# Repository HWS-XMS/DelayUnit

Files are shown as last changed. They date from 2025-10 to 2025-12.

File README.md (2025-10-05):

# Precision Trigger Delay System

Configurable digital delay system for Xilinx FPGAs with 5ns resolution.

## Features

- **Resolution**: 5ns (200MHz clock)
- **Delay Range**: 0 to 21.5 seconds
- **Configurable Output Width**: 5ns to any duration
- **Control**: UART @ 1Mbaud with Python API
- **Supported Platforms**:
  - Digilent Arty A7-35T (XC7A35T)
  - Digilent Nexys Video (XC7A200T)

## Quick Start

### Build & Program

Navigate to your target board directory and use the local Makefile:

**For Arty A7:**
```bash
cd targets/arty
make synth         # Synthesize design
make program       # Program FPGA (volatile)
make flash         # Program SPI flash (persistent)
```

**For Nexys Video:**
```bash
cd targets/nexys
make synth         # Synthesize design
make program       # Program FPGA (volatile)
make flash         # Program SPI flash (persistent)
```

### Python Control

```python
from delay_unit import DelayUnit, EdgeType

with DelayUnit() as unit:
    unit.delay_ns = 100
    unit.width_ns = 50
    unit.soft_trigger()
    print(unit.status)
```

### Testing

```bash
cd python
python test_comprehensive.py  # 1000 test combinations
```

## Hardware Setup

### Arty A7-35T

**Soft Trigger Testing:**
- Jumper: JA Pin 3 → JA Pin 1
- Scope Ch1: JA Pin 3 (trigger)
- Scope Ch2: JA Pin 2 (delayed output)

**Pmod JA Pinout:**
- Pin 1 (G13): External trigger input
- Pin 2 (B11): Delayed trigger output
- Pin 3 (A11): Soft trigger output

### Nexys Video (XC7A200T)

**Soft Trigger Testing:**
- Jumper: JA Pin 3 → JA Pin 1
- Scope Ch1: JA Pin 3 (trigger)
- Scope Ch2: JA Pin 2 (delayed output)

**Pmod JA Pinout:**
- Pin 1 (AB22): External trigger input
- Pin 2 (AB21): Delayed trigger output
- Pin 3 (AB20): Soft trigger output

## Architecture

- **CDC_EDGE_DETECT**: Clock domain crossing with edge detection
- **CONFIGURABLE_DELAY**: Programmable delay with configurable output width
- **UART_RX/TX**: UART communication @ 1Mbaud
- **Clock**: 100MHz input → 200MHz system clock via MMCM

## UART Commands

| Command | Code | Data | Description |
|---|---|---|---|
| SET_COARSE | 0x01 | 4 bytes | Set delay (cycles) |
| GET_COARSE | 0x02 | - | Get delay |
| SET_WIDTH | 0x08 | 4 bytes | Set output width (cycles) |
| GET_WIDTH | 0x09 | - | Get output width |
| SOFT_TRIGGER | 0x07 | - | Generate trigger |
| GET_STATUS | 0x05 | - | Get trigger count + delay |
| RESET_COUNT | 0x06 | - | Reset counter |

## License

MIT

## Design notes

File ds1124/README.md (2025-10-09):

# DS1124 8-Bit Programmable Delay Line Driver

SystemVerilog implementation of a driver for the DS1124 programmable delay IC.

## ⚠️ Important Hardware Requirements

**The DS1124 operates at 5V logic levels.** Most modern FPGAs use 3.3V or 1.8V I/O standards, therefore:

### Control Interface Level Shifting
- **Level shifters are REQUIRED** between FPGA and DS1124
- Use bidirectional level shifters for the Q signal (if readback is used)
- Use unidirectional level shifters for CLK, D, and E signals (FPGA → DS1124)
- Ensure level shifters can handle the serial clock frequency (up to 10 MHz)

### Signal Path Level Shifting
- **The actual signal to be delayed ALSO requires level shifting:**
  - INPUT: FPGA output (3.3V/1.8V) → Level Shifter → DS1124 IN (5V)
  - OUTPUT: DS1124 OUT (5V) → Level Shifter → FPGA input (3.3V/1.8V)
- These signal path level shifters must support the full bandwidth of your delayed signal
- Use high-speed level shifters for critical timing paths

Example level shifters:
- TXB0104 (4-channel bidirectional, auto-direction, up to 100 Mbps)
- SN74LVC1T45 (single channel bidirectional, up to 420 Mbps)
- SN74LVC2T45 (dual channel bidirectional)
- SN74LVC1G125 (single channel unidirectional, high-speed)

## Files

- `ds1124_driver.sv` - Main driver module
- `ds1124_driver_tb.sv` - Comprehensive testbench
- `test_*.sv` - Auxiliary test files for specific features

## Features

- 8-bit delay control (0-255 steps, 0.25ns per step)  
- 3-wire serial interface (CLK, D, E)
- Configurable system clock frequency
- Optional non-destructive readback
- Automatic settling time calculation

## Usage

```systemverilog
ds1124_driver #(
    .SYS_CLK_FREQ(100_000_000),  // 100 MHz
    .CLK_DIV(4),                  // Divide by 4
    .READBACK_EN(1)               // Enable readback
) u_ds1124 (
    .clk(clk),
    .rst(rst),
    .delay_value(delay_value),
    .en(en),
    .ready(ready),
    .ds1124_clk(ds1124_clk),
    .ds1124_d(ds1124_d),
    .ds1124_e(ds1124_e),
    .ds1124_q(ds1124_q),
    .read_delay(read_delay),
    .current_delay(current_delay),
    .read_valid(read_valid)
);
```

## Testing

Run the comprehensive testbench:
```bash
iverilog -g2012 -o ds1124_tb ds1124_driver.sv ds1124_driver_tb.sv
vvp ds1124_tb
```

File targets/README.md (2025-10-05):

# Board Targets

This directory contains board-specific build configurations for the Precision Trigger Delay System.

## Available Targets

### arty/
Digilent Arty A7-35T (XC7A35TICSG324-1L)
- 100MHz system clock → 200MHz via MMCM
- Pmod JA connections for trigger I/O
- USB-UART for control interface

### nexys/
Digilent Nexys Video (XC7A200TSBG484-1)
- 100MHz system clock → 200MHz via MMCM
- Pmod JA connections for trigger I/O
- USB-UART for control interface

## Target Structure

Each target directory contains:

```
targetname/
├── Makefile          # Board-specific build rules
├── synth.tcl         # Vivado synthesis script
├── program.tcl       # FPGA programming (volatile)
├── flash.tcl         # Flash programming (persistent)
├── constraints.xdc   # Pin assignments & timing
└── build/           # Generated during synthesis
    ├── trigger_delay.bit
    ├── trigger_delay.mcs (for flash)
    └── *.rpt (reports)
```

## Building

### From project root:
```bash
make arty-synth      # Synthesize Arty target
make arty-program    # Program Arty FPGA
make arty-flash      # Program Arty flash

make nexys-synth     # Synthesize Nexys target
make nexys-program   # Program Nexys FPGA
make nexys-flash     # Program Nexys flash
```

### From target directory:
```bash
cd arty              # or nexys
make synth           # Synthesize
make program         # Program FPGA
make flash           # Program flash
make clean           # Clean build
```

## Pin Mappings

### Arty A7-35T Pmod JA
- **Pin 1 (G13)**: External trigger input
- **Pin 2 (B11)**: Delayed trigger output
- **Pin 3 (A11)**: Soft trigger output

### Nexys Video Pmod JA
- **Pin 1 (AB22)**: External trigger input
- **Pin 2 (AB21)**: Delayed trigger output
- **Pin 3 (AB20)**: Soft trigger output

## Common Operations

**Clean all targets:**
```bash
cd ../..
make clean
```

**View build reports:**
```bash
cd arty/build
ls *.rpt
```

**Test bitstream:**
```bash
make synth
make program
cd ../../python
python test_comprehensive.py
```

## Adding New Targets

1. Copy an existing target directory
2. Rename and update these files:
   - `constraints.xdc` - Pin assignments
   - `synth.tcl` - FPGA part number
   - `program.tcl` - Device ID
   - `flash.tcl` - Flash part number
3. Add rules to top-level Makefile
4. Document in this README

## Notes

- All targets share the same RTL in `../../rtl/`
- Build outputs are isolated per target
- FPGA programming requires Vivado installed
- Flash programming requires JTAG connection

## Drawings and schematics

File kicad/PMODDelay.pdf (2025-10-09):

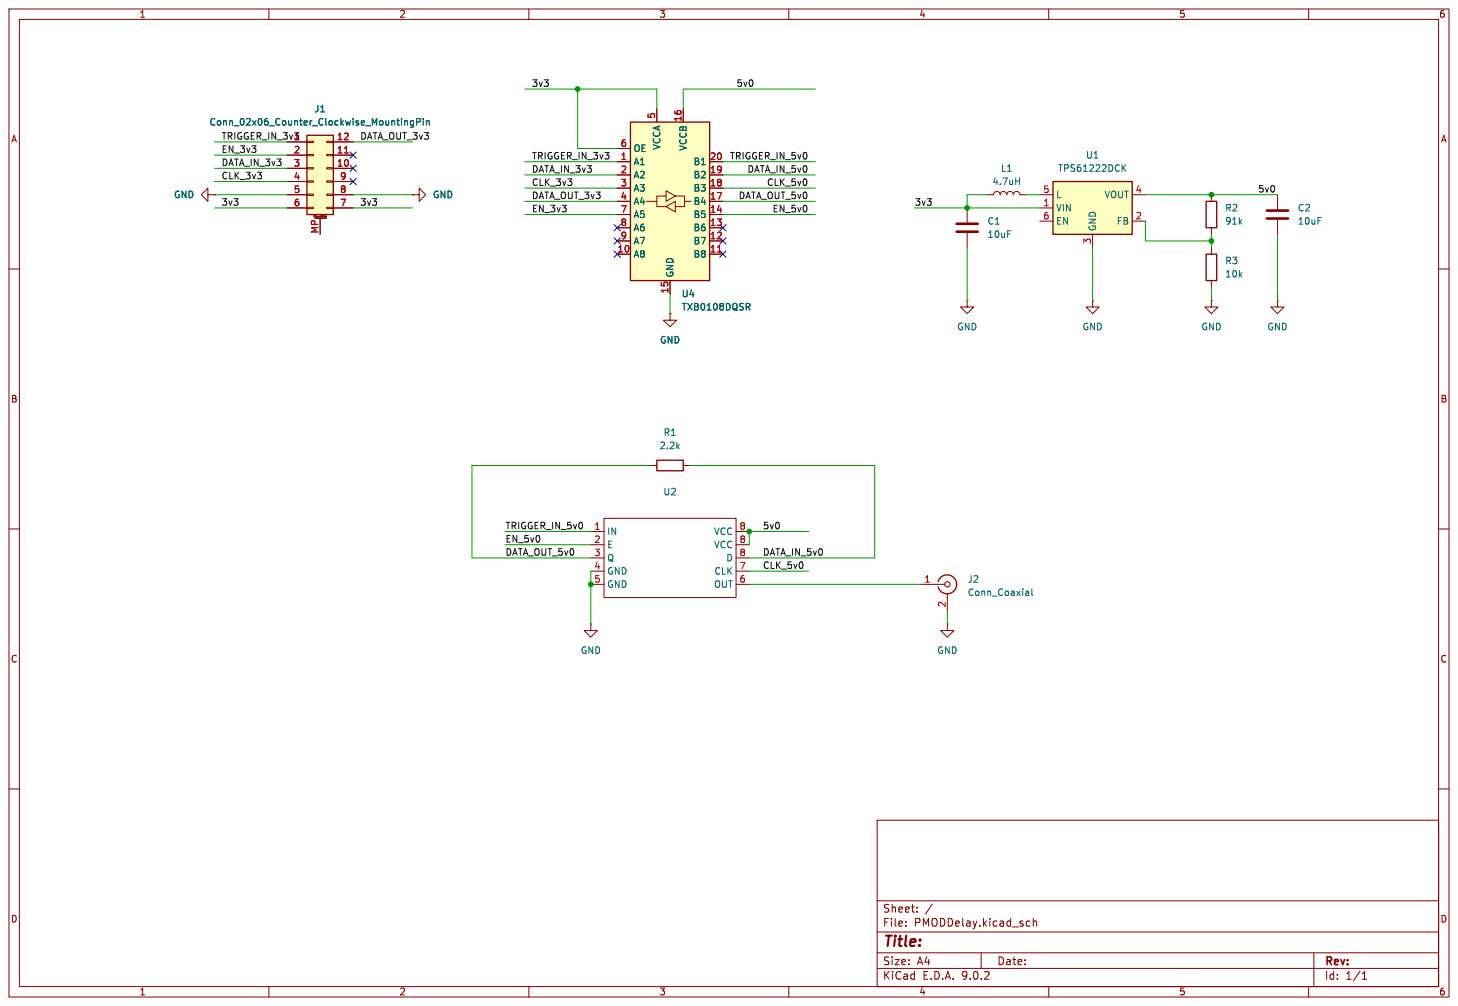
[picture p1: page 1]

5 GND 15 VCCB 16 B1 20 B2 19 B3 18 B4 17 B5 14 B6 13 B7 12 B8 11 GND GND

Id: 1/1 Title: File: PMODDelay.kicad_sch Sheet: /

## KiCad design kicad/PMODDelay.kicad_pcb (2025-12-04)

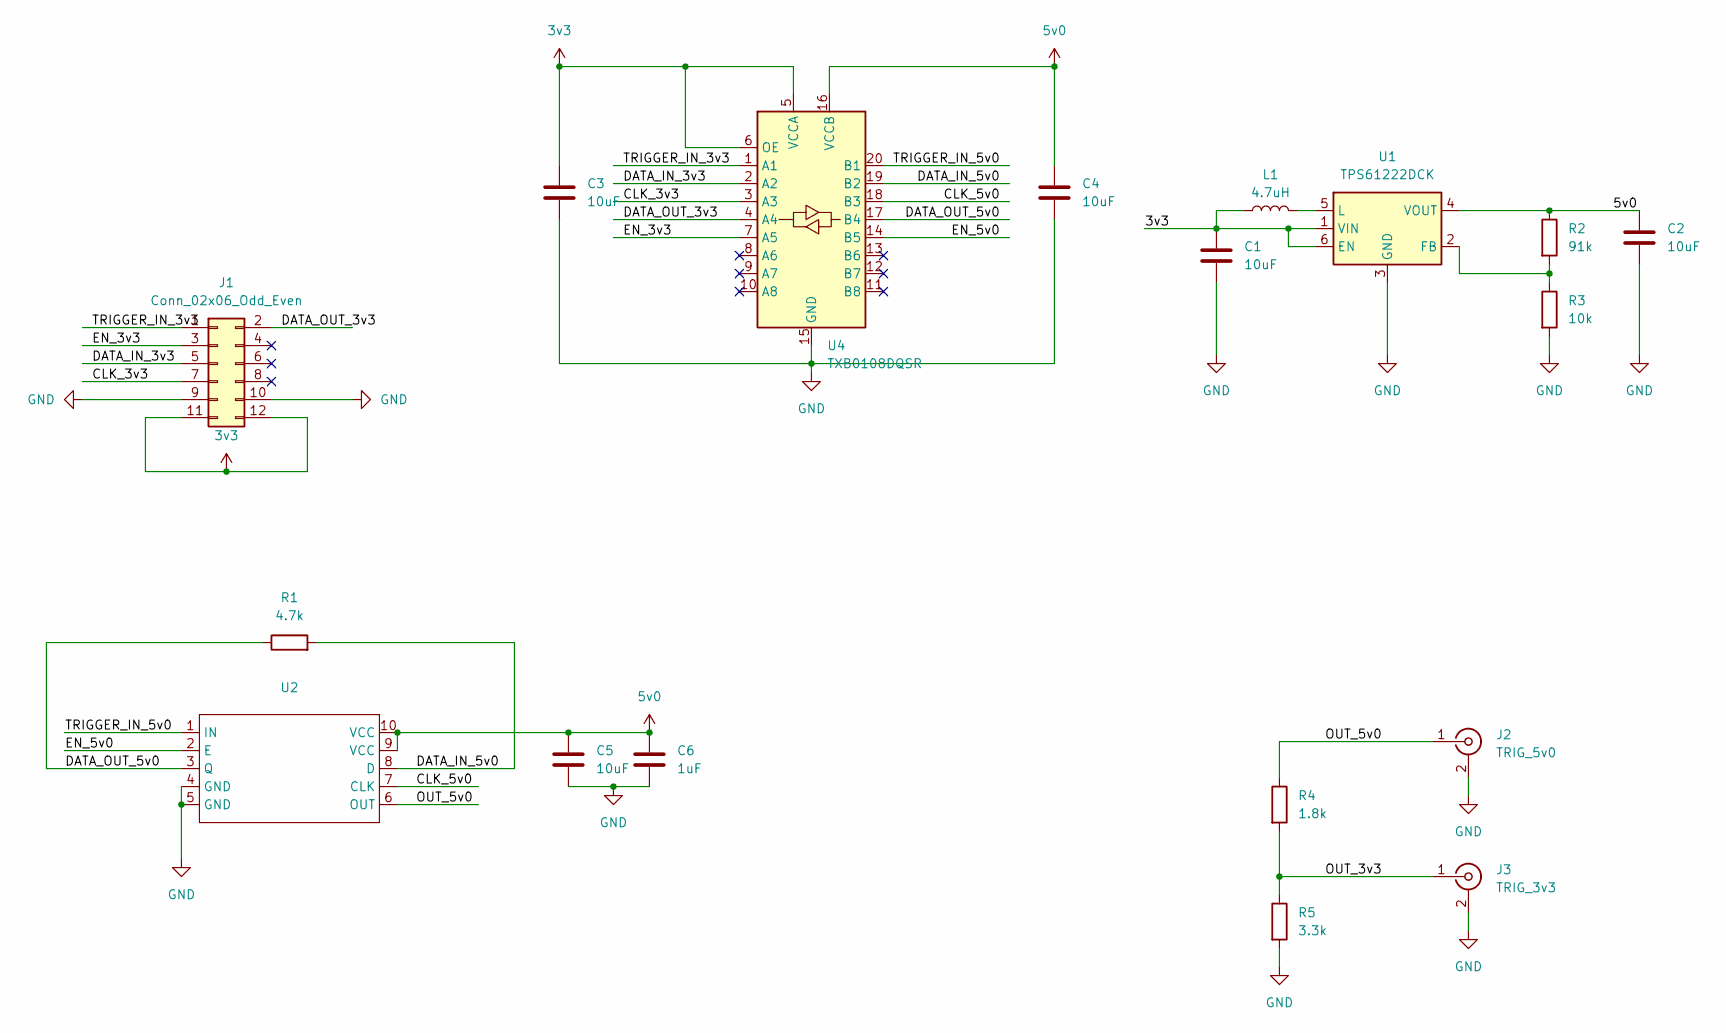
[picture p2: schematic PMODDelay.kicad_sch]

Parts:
C1, C2: 10uF; C_0805_2012Metric
C3, C4, C5: 10uF; C_0805_2012Metric_Pad1.18x1.45mm_HandSolder
C6: 1uF; C_0805_2012Metric_Pad1.18x1.45mm_HandSolder
J1: Conn_02x06_Odd_Even; PinHeader_2x06_P2.54mm_Horizontal
J2: TRIG_5v0; SMA_Amphenol_901-144_Vertical
J3: TRIG_3v3; SMA_Amphenol_901-144_Vertical
L1: 4.7uH; R_0805_2012Metric
R1: 4.7k; R_0805_2012Metric
R2: 91k; R_0805_2012Metric
R3: 10k; R_0805_2012Metric
R4: 1.8k; R_0805_2012Metric_Pad1.20x1.40mm_HandSolder
R5: 3.3k; R_0805_2012Metric_Pad1.20x1.40mm_HandSolder
U1: TPS61222DCK; Texas_R-PDSO-G6
U2: TSSOP-10_3x3mm_P0.5mm
U4: TXB0108DQSR; USON-20_2x4mm_P0.4mm

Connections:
3v3: C1.1, C3.1, J1.11, J1.12, L1.1, U1.1 (VIN), U1.6 (EN), U4.5 (VCCA), U4.6 (OE)
5v0: C2.1, C4.1, C5.1, C6.1, R2.1, U1.4 (VOUT), U2.9 (VCC), U2.10 (VCC), U4.16 (VCCB)
/CLK_3v3: J1.7, U4.3 (A3)
/CLK_5v0: U2.7 (CLK), U4.18 (B3)
/DATA_IN_3v3: J1.5, U4.2 (A2)
/DATA_IN_5v0: R1.2, U2.8 (D), U4.19 (B2)
/DATA_OUT_3v3: J1.2, U4.4 (A4)
/DATA_OUT_5v0: R1.1, U2.3 (Q), U4.17 (B4)
/EN_3v3: J1.3, U4.7 (A5)
/EN_5v0: U2.2 (E), U4.14 (B5)
/OUT_3v3: J3.1 (In), R4.2, R5.1
/OUT_5v0: J2.1 (In), R4.1, U2.6 (OUT)
/TRIGGER_IN_3v3: J1.1, U4.1 (A1)
/TRIGGER_IN_5v0: U2.1 (IN), U4.20 (B1)
GND: C1.2, C2.2, C3.2, C4.2, C5.2, C6.2, J1.9, J1.10, J2.2 (Ext), J3.2 (Ext), R3.2, R5.2, U1.3 (GND), U2.4 (GND), U2.5 (GND), U4.15 (GND)
unnamed: R2.2, R3.1, U1.2 (FB)
unnamed: L1.2, U1.5 (L)

Board: 2 copper layers, 18 parts (0 on the bottom side), 17 nets, no tracks yet.

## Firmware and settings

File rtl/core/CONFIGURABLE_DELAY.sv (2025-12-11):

`timescale 1ns / 1ps

module CONFIGURABLE_DELAY #(
    parameter MAX_DELAY_BITS = 32
)(
    input  logic clk,               // Main clock (200MHz)
    input  logic clk_offset,        // Phase-shifted clock for pulse start
    input  logic clk_width,         // Phase-shifted clock for pulse end
    input  logic rst,
    input  logic trigger_in,        // Already a pulse from CDC edge detect
    output logic trigger_out,
    input  logic [MAX_DELAY_BITS-1:0] delay_cycles,
    input  logic delay_update,
    input  logic [MAX_DELAY_BITS-1:0] output_width_cycles,
    input  logic width_update
);

    logic [MAX_DELAY_BITS-1:0] current_delay;
    logic [MAX_DELAY_BITS-1:0] current_width;
    logic [MAX_DELAY_BITS-1:0] counter;
    logic [MAX_DELAY_BITS-1:0] width_counter;
    logic counting;
    logic trigger_pending;

    // Coarse timing signals (main clock domain)
    logic coarse_delay_done;    // Coarse delay counter reached zero
    logic coarse_width_done;    // Coarse width counter reached zero

    // Fine timing signals (phase-shifted clock domains)
    logic output_set;           // Set by clk_offset after coarse_delay_done
    logic output_reset;         // Set by clk_width after coarse_width_done

    // Output flip-flop
    logic output_active;

    // =========================================================================
    // Configuration registers (main clock domain)
    // =========================================================================
    always_ff @(posedge clk) begin
        if (rst) begin
            current_delay <= '0;
            current_width <= 32'd1;  // Default 1 cycle (5ns)
        end else begin
            if (delay_update) begin
                current_delay <= delay_cycles;
            end
            if (width_update) begin
                current_width <= output_width_cycles;
            end
        end
    end

    // =========================================================================
    // Coarse delay counter (main clock domain)
    // =========================================================================
    always_ff @(posedge clk) begin
        if (rst) begin
            counter <= '0;
            counting <= 1'b0;
            trigger_pending <= 1'b0;
            coarse_delay_done <= 1'b0;
        end else begin
            coarse_delay_done <= 1'b0;

            // trigger_in is already a single-cycle pulse from CDC
            if (trigger_in && !counting && !output_active) begin
                if (current_delay == '0) begin
                    // Zero delay: immediately signal coarse done
                    coarse_delay_done <= 1'b1;
                end else begin
                    counting <= 1'b1;
                    counter <= current_delay - 1'b1;
                end
            end else if (trigger_in && counting) begin
                trigger_pending <= 1'b1;
            end

            if (counting) begin
                if (counter == '0) begin
                    coarse_delay_done <= 1'b1;

                    if (trigger_pending) begin
                        counter <= current_delay - 1'b1;
                        trigger_pending <= 1'b0;
                    end else begin
                        counting <= 1'b0;
                    end
                end else begin
                    counter <= counter - 1'b1;
                end
            end
        end
    end

    // =========================================================================
    // Coarse width counter (main clock domain)
    // =========================================================================
    always_ff @(posedge clk) begin
        if (rst) begin
            width_counter <= '0;
            coarse_width_done <= 1'b0;
        end else begin
            coarse_width_done <= 1'b0;

            if (coarse_delay_done) begin
                // Start width counter when delay is done
                if (current_width == '0 || current_width == 32'd1) begin
                    // Zero or one cycle width: immediately signal done
                    coarse_width_done <= 1'b1;
                end else begin
                    width_counter <= current_width - 1'b1;
                end
            end else if (width_counter > 0) begin
                if (width_counter == 32'd1) begin
                    coarse_width_done <= 1'b1;
                    width_counter <= '0;
                end else begin
                    width_counter <= width_counter - 1'b1;
                end
            end
        end
    end

    // =========================================================================
    // Fine edge control - SET pulse (clk_offset domain)
    // Synchronize coarse_delay_done into clk_offset domain and generate SET
    // =========================================================================
    logic coarse_delay_done_sync1, coarse_delay_done_sync2;
    logic coarse_delay_done_edge;
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

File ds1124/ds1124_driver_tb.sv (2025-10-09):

//-----------------------------------------------------------------------------
// DS1124 Driver Testbench
//-----------------------------------------------------------------------------
// Comprehensive testbench for verifying DS1124 driver functionality
//
// Tests:
// 1. Basic write operations
// 2. Timing verification (setup/hold times)
// 3. Back-to-back writes
// 4. Readback functionality
// 5. Reset behavior
// 6. Edge cases (0x00, 0xFF)
//
//-----------------------------------------------------------------------------

`timescale 1ns/1ps

module ds1124_driver_tb;

    //-------------------------------------------------------------------------
    // Parameters
    //-------------------------------------------------------------------------
    parameter CLK_PERIOD = 10;  // 100MHz clock (10ns period)
    parameter CLK_DIV = 4;
    parameter READBACK_EN = 1;
    
    //-------------------------------------------------------------------------
    // DUT Signals
    //-------------------------------------------------------------------------
    logic        clk;
    logic        rst;
    logic [7:0]  delay_value;
    logic        en;
    logic        ready;
    
    logic        ds1124_clk;
    logic        ds1124_d;
    logic        ds1124_e;
    logic        ds1124_q;
    
    logic        read_delay;
    logic [7:0]  current_delay;
    logic        read_valid;
    
    //-------------------------------------------------------------------------
    // Test Variables
    //-------------------------------------------------------------------------
    logic [7:0]  captured_data = 8'h00;
    logic [7:0]  ds1124_internal_reg = 8'h00;
    logic [7:0]  last_written_value = 8'h00;  // Track last written value for verification
    int          test_cnt;
    int          error_cnt;
    bit          verbose = 1;
    
    //-------------------------------------------------------------------------
    // Clock Generation
    //-------------------------------------------------------------------------
    initial begin
        clk = 0;
        forever #(CLK_PERIOD/2) clk = ~clk;
    end
    
    //-------------------------------------------------------------------------
    // DUT Instantiation
    //-------------------------------------------------------------------------
    ds1124_driver #(
        .CLK_DIV(CLK_DIV),
        .READBACK_EN(READBACK_EN)
    ) dut (
        .clk(clk),
        .rst(rst),
        .delay_value(delay_value),
        .en(en),
        .ready(ready),
        .ds1124_clk(ds1124_clk),
        .ds1124_d(ds1124_d),
        .ds1124_e(ds1124_e),
        .ds1124_q(ds1124_q),
        .read_delay(read_delay),
        .current_delay(current_delay),
        .read_valid(read_valid)
    );
    
    //-------------------------------------------------------------------------
    // DS1124 Model (simplified behavioral model)
    //-------------------------------------------------------------------------
    logic [7:0] readback_reg;  // Separate register for readback
    
    always @(posedge ds1124_clk) begin
        if (ds1124_e) begin
            // Shift in new data
            captured_data = {captured_data[6:0], ds1124_d};
            // Shift readback register for Q output
            readback_reg = {readback_reg[6:0], 1'b0};
        end
    end
    
    always @(negedge ds1124_e) begin
        // Latch the captured value when E falls
        ds1124_internal_reg = captured_data;
        if (verbose) $display("[%0t] DS1124 Model: Latched value = 0x%02X", $time, captured_data);
    end
    
    always @(posedge ds1124_e) begin
        // Load readback register at start of shift operation
        readback_reg = ds1124_internal_reg;
    end
    
    // Q output presents MSB of readback register
    assign ds1124_q = readback_reg[7];
    
    //-------------------------------------------------------------------------
    // Timing Checker Tasks
    //-------------------------------------------------------------------------
    task automatic check_setup_hold_timing();
        real t_data_setup;
        real t_clk_rise;
        real t_data_change;
        logic last_d;
        
        // Monitor setup time (tDSC = 30ns min)
        fork
            begin
                while(ds1124_e) begin
                    @(ds1124_d);  // Wait for data change
                    t_data_change = $realtime;
                    last_d = ds1124_d;
                    
                    @(posedge ds1124_clk);  // Wait for next clock edge
                    t_clk_rise = $realtime;
                    t_data_setup = t_clk_rise - t_data_change;
                    
                    if (t_data_setup < 30.0) begin
                        $error("[%0t] Setup time violation! tDSC = %0.2fns (min 30ns)", 
                               $time, t_data_setup);
                        error_cnt++;
                    end
                end
            end
        join_none
    endtask
    
    task automatic check_clock_frequency();
        real t_last_rise;
        real t_curr_rise;
        real t_period;
        int clk_count = 0;
        
        // Monitor clock frequency (max 10MHz = min 100ns period)
        @(posedge ds1124_e);  // Wait for E to go high
        
        while(ds1124_e) begin
            @(posedge ds1124_clk);
            t_curr_rise = $realtime;
            
            if (clk_count > 0) begin
                t_period = t_curr_rise - t_last_rise;
                if (t_period < 100.0) begin
                    $error("[%0t] Clock frequency violation! Period = %0.2fns (min 100ns for 10MHz)", 
                           $time, t_period);
                    error_cnt++;
                end
            end
            
            t_last_rise = t_curr_rise;
            clk_count++;
        end
    endtask
    
    task automatic check_enable_timing();
        real t_e_high_start;
        real t_e_high_end;
        real t_e_pulse_width;
        
        // Check E pulse width (tEW min 50ns)
        @(posedge ds1124_e);
        t_e_high_start = $realtime;
        
        @(negedge ds1124_e);
        t_e_high_end = $realtime;
        t_e_pulse_width = t_e_high_end - t_e_high_start;
        
        // E should be high for at least 8 clock cycles
        if (t_e_pulse_width < 50.0) begin
            $error("[%0t] Enable pulse width violation! tEW = %0.2fns (min 50ns)", 
                   $time, t_e_pulse_width);
            error_cnt++;
        end
    endtask
    
    //-------------------------------------------------------------------------
    // Test Tasks
    //-------------------------------------------------------------------------
    task reset_dut();
        if (verbose) $display("[%0t] Applying reset", $time);
        rst = 1;
        en = 0;
        read_delay = 0;
        delay_value = 8'h00;
        repeat(5) @(posedge clk);
        rst = 0;
        repeat(5) @(posedge clk);
    endtask
    
    task write_delay(input logic [7:0] value);
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

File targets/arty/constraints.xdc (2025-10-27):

## Constraints file for Trigger Delay System on Arty A7-35
## Based on the master XDC file

## Clock signal - 100 MHz system clock
set_property -dict { PACKAGE_PIN E3    IOSTANDARD LVCMOS33 } [get_ports { clk }]; #IO_L12P_T1_MRCC_35 Sch=gclk[100]
create_clock -add -name sys_clk_pin -period 10.00 -waveform {0 5} [get_ports { clk }];

## Reset button - Use Button 0 for system reset
set_property -dict { PACKAGE_PIN D9    IOSTANDARD LVCMOS33 } [get_ports { rst }]; #IO_L6N_T0_VREF_16 Sch=btn[0]

## LEDs - Show trigger counter lower 4 bits
set_property -dict { PACKAGE_PIN H5    IOSTANDARD LVCMOS33 } [get_ports { leds[0] }]; #IO_L24N_T3_35 Sch=led[4]
set_property -dict { PACKAGE_PIN J5    IOSTANDARD LVCMOS33 } [get_ports { leds[1] }]; #IO_25_35 Sch=led[5]
set_property -dict { PACKAGE_PIN T9    IOSTANDARD LVCMOS33 } [get_ports { leds[2] }]; #IO_L24P_T3_A01_D17_14 Sch=led[6]
set_property -dict { PACKAGE_PIN T10   IOSTANDARD LVCMOS33 } [get_ports { leds[3] }]; #IO_L24N_T3_A00_D16_14 Sch=led[7]

## USB-UART Interface - For communication with host PC
set_property -dict { PACKAGE_PIN D10   IOSTANDARD LVCMOS33 } [get_ports { uart_tx }]; #IO_L19N_T3_VREF_16 Sch=uart_rxd_out (FPGA TX -> USB RX)
set_property -dict { PACKAGE_PIN A9    IOSTANDARD LVCMOS33 } [get_ports { uart_rx }]; #IO_L14N_T2_SRCC_16 Sch=uart_txd_in (USB TX -> FPGA RX)

## Trigger Input - Using Pmod JA Pin 1
## EXTERNAL mode: receives trigger from DuT
## INTERNAL mode: receives trigger from PIN3 via jumper
set_property -dict { PACKAGE_PIN G13   IOSTANDARD LVCMOS33 } [get_ports { trigger_in }]; #IO_0_15 Sch=ja[1]

## Trigger Delayed Output - Using Pmod JA Pin 2 for delayed trigger output
## Outputs delayed version of trigger received on PIN1
set_property -dict { PACKAGE_PIN B11   IOSTANDARD LVCMOS33 } [get_ports { trigger_delayed_out }]; #IO_L4P_T0_15 Sch=ja[2]

## Soft Trigger Output - Using Pmod JA Pin 3 for soft trigger pulse (for debugging/monitoring)
set_property -dict { PACKAGE_PIN A11   IOSTANDARD LVCMOS33 } [get_ports { soft_trigger_out }]; #IO_L4N_T0_15 Sch=ja[3]

## Optional: Additional trigger I/O on Pmod JB for differential signals
## Uncomment if using differential trigger signals
# set_property -dict { PACKAGE_PIN E15   IOSTANDARD LVCMOS33 } [get_ports { trigger_in_p }]; #IO_L11P_T1_SRCC_15 Sch=jb_p[1]
# set_property -dict { PACKAGE_PIN E16   IOSTANDARD LVCMOS33 } [get_ports { trigger_in_n }]; #IO_L11N_T1_SRCC_15 Sch=jb_n[1]
# set_property -dict { PACKAGE_PIN D15   IOSTANDARD LVCMOS33 } [get_ports { trigger_out_p }]; #IO_L12P_T1_MRCC_15 Sch=jb_p[2]
# set_property -dict { PACKAGE_PIN C15   IOSTANDARD LVCMOS33 } [get_ports { trigger_out_n }]; #IO_L12N_T1_MRCC_15 Sch=jb_n[2]

## Configuration options
set_property CONFIG_VOLTAGE 3.3 [current_design]
set_property CFGBVS VCCO [current_design]

## Timing constraints for I/O
set_input_delay -clock [get_clocks sys_clk_pin] -min -add_delay 2.000 [get_ports trigger_in]
set_input_delay -clock [get_clocks sys_clk_pin] -max -add_delay 5.000 [get_ports trigger_in]
set_output_delay -clock [get_clocks sys_clk_pin] -min -add_delay -1.000 [get_ports trigger_delayed_out]
set_output_delay -clock [get_clocks sys_clk_pin] -max -add_delay 2.000 [get_ports trigger_delayed_out]
set_output_delay -clock [get_clocks sys_clk_pin] -min -add_delay -1.000 [get_ports soft_trigger_out]
set_output_delay -clock [get_clocks sys_clk_pin] -max -add_delay 2.000 [get_ports soft_trigger_out]

## UART timing constraints - for 1Mbaud
set_input_delay -clock [get_clocks sys_clk_pin] -min -add_delay 2.000 [get_ports uart_rx]
set_input_delay -clock [get_clocks sys_clk_pin] -max -add_delay 5.000 [get_ports uart_rx]
set_output_delay -clock [get_clocks sys_clk_pin] -min -add_delay -1.000 [get_ports uart_tx]
set_output_delay -clock [get_clocks sys_clk_pin] -max -add_delay 2.000 [get_ports uart_tx]

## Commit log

2025-09-30 Picosecond-precision trigger delay system with MMCM
    - Implemented configurable digital delay with 20ps resolution
    - MMCM-based fine delay using 887.5MHz VCO (8.875x multiplier)
    - Coarse delay in clock cycles + fine delay in 20ps increments
    - Full 10ns coverage with clean 20ps steps
    - UART control interface with Python script
    - Support for edge detection (rising/falling/both)
    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
2025-09-30 Reorganize project structure for better maintainability
    - Organized RTL into core/, mmcm/, uart/ subdirectories
    - Moved testbenches to tb/
    - Moved constraints to constraints/
    - Created scripts/ for vivado and python tools
    - Updated all include paths for new structure
    - Added comprehensive README with documentation
    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
2025-09-30 Simplify project: focus on MMCM version for Xilinx only
    - Removed IceStick support (MMCM is Xilinx-specific)
    - Removed non-MMCM versions (keeping only 20ps precision version)
    - Removed unused docs directory
    - Renamed constraints to constraints_arty (board-specific)
    - Simplified Makefile and synthesis scripts
    - Updated README for streamlined structure
2025-09-30 Fix critical issues found in code review
    - Fixed module name from TRIGGER_DELAY_TOP_MMCM to TRIGGER_DELAY_TOP
    - Corrected VCO frequency comment (887.5MHz, not 1GHz)
    - Note: Simulation requires Xilinx tools for MMCM primitives
    [TRIGGER_DELAY_TOP.sv]
2025-10-07 Introducing PMOD Delay Module
    [PMODDelay.kicad_pcb, PMODDelay.kicad_sch]
2025-10-09 Introducing DS1124U Driver, updating PCB.
    [PMODDelay.kicad_pcb, PMODDelay.kicad_sch]
2025-10-15 Add custom VID/PID support and FTDI EEPROM programming tools
2025-12-04 Updating Schematic
    [PMODDelay.kicad_pcb, PMODDelay.kicad_sch]
